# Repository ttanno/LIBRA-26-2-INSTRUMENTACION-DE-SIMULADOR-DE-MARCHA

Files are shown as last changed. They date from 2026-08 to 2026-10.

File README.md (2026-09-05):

# LIBRA — Instrumentación de Simulador de Marcha

**Plataforma móvil instrumentada para simulador de marcha**, orientada a la validación de prótesis transtibiales mediante sensórica embebida (IMU + celda de carga) y adquisición de datos sincronizada.

| | |
|---|---|
| **Curso** | DPB4 — Proyecto de Investigación |
| **Institución** | Pontificia Universidad Católica del Perú (PUCP) |
| **Alumno** | Alessandro Jesus Felix Tello |
| **Asesor** | Dante Angel Elias Giordano |
| **Estado** | En curso — Semana 4: pruebas de firmware de IMU (BNO055/MPU6050) y prototipos de referencia de posición absoluta (homing) para la plataforma |

---

## Índice

- [Descripción del proyecto](#descripción-del-proyecto)
- [Objetivos específicos](#objetivos-específicos)
- [Alcance](#alcance)
- [Nota de prioridad (Semana 3)](#nota-de-prioridad-semana-3)
- [Estructura del repositorio](#estructura-del-repositorio)
- [Estado del arte](#estado-del-arte)
- [Reportes semanales](#reportes-semanales)
- [Requerimientos técnicos derivados](#requerimientos-técnicos-derivados)

---

## Descripción del proyecto

En el laboratorio ya existe una plataforma mecánica de simulación de marcha (traslación horizontal por riel + cadena, traslación vertical por husillo y motor paso a paso, y un punto de flexo-extensión en el soporte de la prótesis), construida en un proyecto anterior. Este proyecto parte de esa base ya construida para **integrar sensores** (IMU y celda de carga), su electrónica de adquisición y un software de registro sincronizado, con el fin de validar prótesis transtibiales bajo cargas y cinemática trazables a normas ISO. El diseño mecánico puede implicar tanto soportes/adaptadores externos como modificaciones a la estructura existente, según lo que requiera la integración final de los sensores.

## Objetivos específicos

1. **Diseño mecánico** — Diseñar los soportes/adaptadores (y, de ser necesario, modificaciones a la estructura ya existente) para montar la IMU y la celda de carga, preservando la cinemática de la plataforma.
2. **Sistema electrónico** — Seleccionar e integrar sensores de bajo costo (IMU MEMS, celda de carga) dimensionados según las cargas de referencia de ISO 10328.
3. **Software** — Implementar adquisición continua y sincronizada (I2C/SPI para IMU, ADC dedicado para la celda de carga) con registro, visualización y almacenamiento.
4. **Validación** — Definir un protocolo de calibración y validación cruzada (IMU vs. encoder de la plataforma) anclado a ISO 7500-1 e ISO 22675.

## Alcance

La plataforma **sensa de forma continua** (registro/visualización) durante el uso de la prótesis en la simulación. **No** implementa un lazo de control en tiempo real (p. ej. un PID que retroalimente al simulador con los datos del sensor); esto queda como trabajo futuro. Esta distinción simplifica los requerimientos de software: no se exige baja latencia de lazo cerrado, solo sensado sincronizado y confiable.

## Estructura del repositorio

```
LIBRA/
├── Firmware/                           Sketches ESP32 (Arduino) y visores Python de prueba, por sensor/subsistema
│   ├── test_bno055/                    Prueba I2C + sobremuestreo del IMU BNO055, con visor en tiempo real
│   ├── test_mpu6050/                   Prueba del IMU MPU6050 con filtro complementario propio
│   ├── homing_absoluto/                Prototipo de cero absoluto del pivote por acelerómetro (persistente en flash)
│   └── homing_husillo_hall/            Prototipo de homing del eje del husillo con sensor Hall + imán
├── Estado-del-arte/                    Fichas de lectura, fuentes primarias (PDF) y la síntesis bibliográfica
│   ├── ISO/                            Normas y ensayos estructurales de prótesis
│   ├── REFERENCIA DE POSICION ABSOLUTA/  Arquitecturas de referencia absoluta sin goniómetro (CNC, robótica, laboratorios de marcha)
│   ├── SENSORES DE FUERZA/
│   │   ├── PYLON/                      Celda de carga en la interfaz pylon-plataforma: strain gauge, sensor magnético, comparativa de candidatas
│   │   └── GRF-AMTI/                   Plataforma de fuerza AMTI BP400600 (manuales, pinout, integración)
│   ├── SIMULADOR DE MARCHA/            Diseño mecánico de plataformas y bancos de prueba
│   ├── SOFTWARE/                       Arquitecturas de software embebido multi-sensor
│   ├── Revision bibliografica - Semana 1-2.md   Revisión bibliográfica consolidada (40 referencias, formato IEEE)
│   └── Sensores-LIBRA-Presentacion.pptx         Comparativa de sensores de fuerza, distancia y ángulo (soporte visual)
├── Evidencias/                         Fotos propias del equipo de laboratorio (no bibliográficas, reutilizables entre semanas)
│   ├── simulador/                      Simulador físico existente y método de marcadores M1-M4
│   ├── pruebas-imu-S4/                 Fotos de las pruebas de IMU (banco de protoboard) y del montaje sobre el pylon real (S4)
│   └── arquitectura-sensores-AMTI-S2.png   Diagrama de arquitectura de sensores por DOF (Semana 2)
├── Reportes-Semanales/                 Informes y reportes de avance, por semana
│   ├── S1/
│   │   ├── S1 - Informe Semanal...     Informe semanal (formato PUCP)
│   │   ├── S1 - Reporte de Avance...   Reporte de avance (formato PUCP)
│   │   └── Pendientes.md               Lista de trabajo de la S1 (cerrada; ítems abiertos trasladados a S3)
│   ├── S2/
│   │   ├── S2 - Informe Semanal...
│   │   ├── S2 - Reporte de Avance...
│   │   └── Resumen-Semana2.md          Resumen narrativo de la S2 (arquitectura por DOF, integración AMTI)
│   ├── S3/
│   │   └── Pendientes.md               Lista de trabajo de la S3 (cerrada; ítems abiertos trasladados a S4)
│   └── S4/
│       ├── Resumen-Semana4.md          Resumen narrativo de la S4 (pruebas de IMU y prototipos de homing)
│       └── Pendientes.md               Lista de trabajo activa (se actualiza semana a semana)
├── Plan de trabajo 1_DPB4 - Proyecto Simulador de marcha (2).pdf
└── README.md
```

## Estado del arte

La [revisión bibliográfica](./Estado-del-arte/Revision%20bibliografica%20-%20Semana%201-2.md) consolida el estado del arte en:

- Simuladores de marcha con sensórica embebida
- Concordancia entre IMU y sistemas ópticos de captura de movimiento
- Calibración y validación de IMU de bajo costo
- Celdas de carga y sensores fuerza-torque en prótesis y bancos de prueba
- Protocolos de calibración de instrumentación en sistemas robóticos/mecatrónicos
- Normas ISO de ensayo estructural de prótesis (ISO 10328, ISO 22675, ISO 7500-1)
- Arquitecturas de software para adquisición sincronizada multi-sensor
- Diseño mecánico de plataformas móviles y bancos de prueba
- Arquitectura electrónica de referencia y ubicación del sensor de fuerza (interfaz pylon–plataforma)
- Taxonomía de principios físicos de sensado de fuerza (strain gauge, magnético, capacitivo, FSR, piezoeléctrico, F/T comercial)

Cada referencia está trazada a su fuente y marcada según su nivel de verificación (confirmada por fuente primaria, corroboración cruzada, o pendiente de verificar). El documento incluye además una síntesis por objetivo específico y la brecha que justifica el proyecto.

Las fuentes originales (PDF y fichas en Markdown) están organizadas por tema en [`Estado-del-arte/`](./Estado-del-arte).

## Reportes semanales

En [`Reportes-Semanales/`](./Reportes-Semanales) se archivan, por semana, el informe de avance y el reporte semanal del proyecto (formato PUCP: resumen ejecutivo, actividades realizadas, planificado vs. ejecutado, dificultades, lecciones aprendidas y próximos pasos).

## Requerimientos técnicos derivados

Resumen de los requerimientos definidos a partir del estado del arte (detalle completo en la [revisión bibliográfica](./Estado-del-arte/Revision%20bibliografica%20-%20Semana%201-2.md#10-requerimientos-técnicos-derivados-cierre-de-semana-2)):

| Componente | Requerimiento orientativo |
|---|---|
| **IMU** | Sensor MEMS de bajo costo (MPU6050 / ICM-20948), muestreo ≥100 Hz, error objetivo <5° con calibración automática sensor-a-segmento |
| **Celda de carga (pylon)** | Rango dimensionado sobre ISO 10328 nivel P5 (≤100 kg): proof load 2240 N, ultimate 4480 N; no linealidad objetivo <8%. Ubicación: interfaz pylon–plataforma (no socket, no suelo), 1 eje axial. La candidata inicial (TAL107F-10kg) resultó subdimensionada — ver comparativa actualizada en [`Estado-del-arte/SENSORES DE FUERZA/PYLON/Comparativa-Sensores-Fuerza-Axial-Pylon.md`](./Estado-del-arte/SENSORES%20DE%20FUERZA/PYLON/Comparativa-Sensores-Fuerza-Axial-Pylon.md) |
| **Plataforma GRF (AMTI)** | AMTI BP400600 ya disponible en el laboratorio; lectura en tiempo real por salida analógica DB25S (Fx,Fy,Fz,Mx,My,Mz) hacia el mismo ADC (ADS1256), en paralelo a la celda de carga |
| **Software** | Adquisición continua por timestamp compartido, I2C/SPI + ADC dedicado, arquitectura modular para agregar sensores sin rediseño |
| **Validación** | Calibración estática/dinámica trazable (ISO 7500-1) + validación cruzada IMU vs. encoder de la plataforma, referenciada a ISO 22675 |
</content>

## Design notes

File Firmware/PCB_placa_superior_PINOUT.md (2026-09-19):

# Pinout de referencia — Placa superior (ESP32 + 2x VL53L1X + entrada HX711)

Referencia de conexionado para la placa que va **arriba** (ESP32-WROOM-32U +
los dos sensores de distancia ToF VL53L1X + entrada para el módulo HX711 +
borneras de tornillo para la celda de carga). El **BNO055 va en una placa
aparte**, montada abajo en la plataforma — no está en este documento (ver
`test_bno055/` y `test_bno055_oversampling/`).

Todos los datos de abajo están verificados contra hojas de datos/documentación
oficial (fuentes al final).

## 0. Topología general: el ESP32 es el único "cerebro"

No hay ningún microcontrolador en la placa de abajo — esa placa es solo el
BNO055 + un conector. **Todo** (HX711, los 2 ToF, y el BNO055) se conecta al
mismo ESP32 de la placa de arriba: HX711 y los ToF directo en la misma
placa, y el BNO055 por un cable/conector entre las dos placas.

Para el BNO055, en vez de compartir el mismo bus I2C de los ToF (que ya tiene
que manejar la secuencia de SHUT + reasignación de direcciones, y le llegaría
por un cable más largo entre placas, con más chance de ruido), conviene usar
el **segundo bus I2C que trae el ESP32** (tiene dos periféricos I2C
independientes por hardware) dedicado solo al BNO055:

| Señal | GPIO | Notas |
|---|---|---|
| SDA2 (bus dedicado al BNO055) | GPIO17 | libre, no strapping, no solo-entrada |
| SCL2 (bus dedicado al BNO055) | GPIO16 | libre, no strapping, no solo-entrada |

Así el BNO055 queda solo en su propio bus (sin competir por direcciones con
los ToF) y el conector entre las dos placas lleva 4 hilos: **3.3V, GND,
GPIO17 (SDA2), GPIO16 (SCL2)**.

## 1. ESP32-WROOM-32U DevKitC — pinout físico de 30 pines

Layout estándar del devkit de 30 pines (el mismo que aparece en el
esquemático, `U6`):

| Columna izquierda (de arriba hacia abajo) | Columna derecha (de arriba hacia abajo) |
|---|---|
| EN | 3V3 |
| VP (GPIO36, solo entrada) | GND |
| VN (GPIO39, solo entrada) | GPIO15 |
| GPIO34 (solo entrada) | GPIO2 |
| GPIO35 (solo entrada) | GPIO0 |
| GPIO32 | GPIO4 |
| GPIO33 | GPIO16 |
| GPIO25 | GPIO17 |
| GPIO26 | GPIO5 |
| GPIO27 | GPIO18 |
| GPIO14 | GPIO19 |
| GPIO12 | GND |
| GPIO13 | GPIO21 |
| GND | RX0 |
| VIN (5V) | TX0 |
| | GPIO22 |
| | GPIO23 |

**Pines a evitar para señales críticas de este diseño:**

- **Strapping pins (afectan el arranque):** GPIO0, GPIO2, GPIO5, GPIO12,
  GPIO15 — no usar para SHUT/XSHUT ni SCK si se puede evitar (un glitch en el
  arranque podría interferir con el modo de boot del ESP32).
- **Solo entrada (no pueden manejar salidas):** GPIO34, GPIO35, GPIO36 (VP),
  GPIO39 (VN) — no sirven para SCK (HX711) ni para SHUT (ToF), que necesitan
  ser salidas. Sí podrían usarse para una señal que solo se lee (ej. un INT
  de un ToF, si se decide rutearlo).
- **Reservados para la flash SPI interna (no exponer, no usar):** GPIO6-11 —
  no vienen en el header de este devkit de 30 pines, así que no aplica acá,
  pero importante no repetirlos si se diseña un módulo ESP32 "pelado" a
  futuro.

## 2. VL53L1X (sensor de distancia ToF, I2C) — pinout del breakout

Pinout típico de un breakout VL53L1X (I2C + XSHUT + interrupción), que
coincide con las etiquetas `VCC/GND/SDA/SCL/INT/SHUT` del esquemático (`U2`,
`U3`):

| Pin del breakout | Función | Notas |
|---|---|---|
| VCC (VIN) | Alimentación | Acepta 3V-5V en la mayoría de los breakouts (traen su propio regulador a la tensión del chip); revisar el datasheet específico del módulo `MYTOF400C-VL53L1X` antes de fijarlo, pero 3.3V del ESP32 es la opción segura |
| GND | Tierra | Común con el ESP32 |
| SCL | Reloj I2C | Al bus I2C del ESP32 (GPIO22 recomendado) — necesita resistencia pull-up (los breakouts suelen traerla integrada, ~10kΩ) |
| SDA | Datos I2C | Al bus I2C del ESP32 (GPIO21 recomendado) — mismo pull-up |
| INT (GPIO1 del chip) | Salida de interrupción, nivel 2.8V | Opcional — se puede dejar sin conectar (NC) si el firmware va a leer por *polling* en vez de por interrupción |
| SHUT (XSHUT) | Reset/apagado, **activo en bajo** | Nivel desplazado (compatible 3V/5V) — **imprescindible un GPIO independiente por cada sensor**, ver Secc. 4 |

**Dirección I2C:** los VL53L1X vienen todos con la dirección fija de fábrica
**0x29**. Como tenés **dos sensores idénticos en el mismo bus**, no se pueden
diferenciar solo por dirección — hay que usar el pin **SHUT** de cada uno
para reconfigurar la dirección de uno de los dos por software en el arranque
(secuencia típica: mantener ambos en reset, sacar a uno del reset,
reasignarle una dirección I2C distinta con `setAddress()` o equivalente de la
librería que se use, y recién ahí sacar al segundo del reset con la
dirección 0x29 que le queda por default).

## 3. HX711 (módulo breakout, no el chip pelado) — pinout

Ya documentado en detalle en
[`test_hx711/INSTRUCCIONES.md`](test_hx711/INSTRUCCIONES.md) — se repite acá
para tener todo junto:

| Pin del módulo (`XWF-HX711` en el esquemático) | Conexión |
|---|---|
| VCC | 3.3V del ESP32 (sin level shifter — ver justificación en `test_hx711/INSTRUCCIONES.md`) |
| GND | GND común |
| DT (DOUT) | GPIO del ESP32, entrada — GPIO32 en el sketch actual |
| SCK (CLK) | GPIO del ESP32, salida — GPIO33 en el sketch actual |
| E+ / E- | A la bornera de tornillo → Rojo/Negro de la celda de carga (excitación) |
| A+ / A- | A la bornera de tornillo → Verde/Blanco de la celda de carga (señal, canal A) |
| B+ / B- | Libres (canal B, ganancia fija 32 — para una segunda celda si hiciera falta) |

**Código de colores de la celda de carga (4 hilos):** Rojo=EXC+, Negro=EXC-,
Verde=SIG+, Blanco=SIG- (verificar contra el datasheet de la celda que se
termine usando — no es 100% universal entre fabricantes).

## 4. Asignación de pines recomendada para esta placa

Juntando todo lo anterior, evitando strapping pins y pines de solo-entrada:

| Señal | GPIO ESP32 | Justificación |
|---|---|---|
| I2C SDA (compartido, ambos ToF) | GPIO21 | pin I2C por default del ESP32 |
| I2C SCL (compartido, ambos ToF) | GPIO22 | pin I2C por default del ESP32 |
| SHUT ToF1 (U3) | GPIO25 | salida, no strapping |
| SHUT ToF2 (U2) | GPIO26 | salida, no strapping |
| HX711 DT | GPIO32 | ya usado en `test_hx711.ino`, mantiene el firmware actual sin cambios |
| HX711 SCK | GPIO33 | ya usado en `test_hx711.ino`, mantiene el firmware actual sin cambios |
| INT ToF1 / ToF2 (opcional) | sin conectar (NC), o GPIO27/GPIO14 si se decide usar interrupciones | no hace falta para lectura por polling |
| I2C SDA2 (bus dedicado, BNO055 en la otra placa) | GPIO17 | segundo periferico I2C del ESP32, ver Secc. 0 |
| I2C SCL2 (bus dedicado, BNO055 en la otra placa) | GPIO16 | segundo periferico I2C del ESP32, ver Secc. 0 |

Con esta asignación, GPIO0/2/5/12/15 (strapping) y GPIO34/35/36/39 (solo
entrada) quedan libres para lo que haga falta después (ej. UART/JTAG de
debug, otro sensor, etc.) sin comprometer el arranque del ESP32 ni necesitar
salidas donde no se puede.

## 5. Siguiente paso

- Confirmar en el datasheet específico del módulo `MYTOF400C-VL53L1X` (no
  solo el chip VL53L1X genérico) el rango de alimentación exacto y si trae
  pull-ups I2C integradas, antes de rutear VCC/SDA/SCL en la placa.
- Escribir el sketch de prueba para los dos VL53L1X con secuencia de
  SHUT + reasignación de dirección I2C (pendiente, ver conversación del
  Firmware — análogo a como se hizo `test_hx711.ino` para la celda).

### Fuentes consultadas

- [ESP32-DevKitC V4 Pinout Diagram + Safe GPIOs](https://esp32.co.uk/esp32-devkitc-v4-pinout-diagram-safe-gpios/) (categorías de pines: input-only, strapping, flash)
- [ESP32 Pinout Reference — Last Minute Engineers](https://lastminuteengineers.com/esp32-pinout-reference/) (layout físico de 30 pines izquierda/derecha)
- [Adafruit VL53L1X — Pinouts](https://learn.adafruit.com/adafruit-vl53l1x/pinouts) (VIN/GND/SCL/SDA/GPIO(INT)/XSHUT, dirección I2C 0x29, nivel logico de XSHUT)
- `Firmware/test_hx711/INSTRUCCIONES.md` (pinout del módulo HX711 y de la celda de carga, ya verificado en este mismo proyecto)

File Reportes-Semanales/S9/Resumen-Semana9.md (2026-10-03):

# Resumen de trabajo — Semana 9

**Período:** 26/09/2026 – 02/10/2026
**Responsable:** Alessandro Jesus Felix Tello

Foco de la semana: diagnóstico y reparación de la conexión del BNO055 tras el cambio de pinout de la S9 (bus I2C dedicado GPIO17/16), calibración del acelerómetro, y una caracterización completa de linealidad/exactitud/histéresis del sensor en todo su rango de interés (0-60°) usando el soporte de arco indexado construido para esto. Se cierra con una simulación de un filtro de corrección lineal y cuánto reduciría el error.

---

## 1. Diagnóstico y reparación de la conexión del BNO055

Al retomar las pruebas sobre el nuevo pinout (`SDA→GPIO17`, `SCL→GPIO16`, bus `Wire1` dedicado — ver `Firmware/PCB_placa_superior_PINOUT.md`), el sensor dejó de responder. El diagnóstico se hizo leyendo el puerto serial directamente y forzando reseteos controlados, en vez de asumir la causa:

1. **Primer síntoma: cero datos por serial**, ni siquiera el mensaje de arranque del sketch. Se descartó un problema de software leyendo el puerto crudo.
2. **Con reset manual (botón físico):** apareció un bucle de **brownout** (`E BOD: Brownout detector was triggered`) — el ESP32 se reseteaba solo por voltaje insuficiente, antes de terminar el `setup()`. Resuelto cambiando de cable/puerto USB (el reset automático por DTR/RTS tampoco funcionaba en esta placa — hay que usar el botón físico).
3. **Con el ESP32 ya estable:** `ERROR: no se detectó el BNO055`. Se verificó el pinout contra el sketch y se aisló el problema desconectando el sensor por completo (arranque limpio sin él, confirmando que no era un problema general de la placa).
4. **Causa raíz encontrada:** un cable había quedado conectado al pin **INT** del BNO055 en vez de a uno de los 4 pines que usa el diseño (VCC, GND, SDA, SCL) — el diseño de LIBRA deja INT, BOOT, PS1, PS0, BL_IND y RST sin conectar a propósito. Corregido el cableado, el sensor volvió a dar datos limpios y estables.

**Lectura:** la mayoría de las "desconexiones" a lo largo de la semana durante las pruebas de ángulos (ver Secc. 3) fueron reincidencias del mismo tipo de problema (cable flojo por el manipuleo constante del soporte), no un problema del sensor o del firmware.

---

## 2. Calibración del acelerómetro (6 posiciones)

Con la conexión ya estable, se corrió `calibrar_acelerometro.py` (apoyar el sensor quieto en 6 orientaciones — las 6 caras de un cubo imaginario). Resultado: `Calib[sys,gyro,accel,mag]` pasó de **0,3,0,0** a **2,3,3,3** — acelerómetro y magnetómetro quedaron en calibración completa (antes sin calibrar). El offset queda guardado en la flash del ESP32, no hace falta repetirlo en cada encendido.

---

## 3. Prueba de linealidad, exactitud e histéresis (0-60°)

### 3.1 Metodología

Usando el soporte de arco indexado (`Firmware/test_wifi_ap_bno055/soporte_angulos_imu/`, 13 posiciones de 0 a 60° cada 5°), se construyó `prueba_angulos_conocidos.py` para automatizar la toma de datos:

- **Disparo automático:** en vez de adivinar cuándo el sensor ya está quieto en la nueva posición, el script exige ver primero que el sensor **se movió** (std > 1.5°) y recién después que **volvió a quedar quieto** (std < 0.05°) antes de arrancar a grabar 30 s. Esto corrigió un bug de la primera versión, que podía disparar la grabación con el sensor todavía en la posición anterior si ya estaba quieto desde antes.
- **Eje usado:** `roll`, no `pitch` — confirmado con datos reales que, con el montaje actual del IMU sobre la plataforma, pitch se queda prácticamente plano (174-176°) sin importar el ángulo aplicado, mientras que roll sí responde.
- **Diseño del experimento:** los 13 ángulos (0° a 60°, cada 5°), con 3 repeticiones cada uno, en **ambas direcciones** (subida 0→60° y bajada 60→0°) — 78 mediciones en total. Repetir en ambas direcciones permite medir histéresis (holgura mecánica del soporte); repetir 3 veces por ángulo permite separar ruido de una captura puntual del error real, y habilita un test de falta de ajuste para la linealidad.
- Varias posiciones se tuvieron que repetir por los cortes de conexión de la Secc. 1 — los archivos descartados (incompletos o con ruido alto) están documentados en el propio script de procesamiento (`Firmware/test_wifi_ap_bno055/visor_python/analizar_linealidad.py`, diccionario `MAPA`).

### 3.2 Resultados

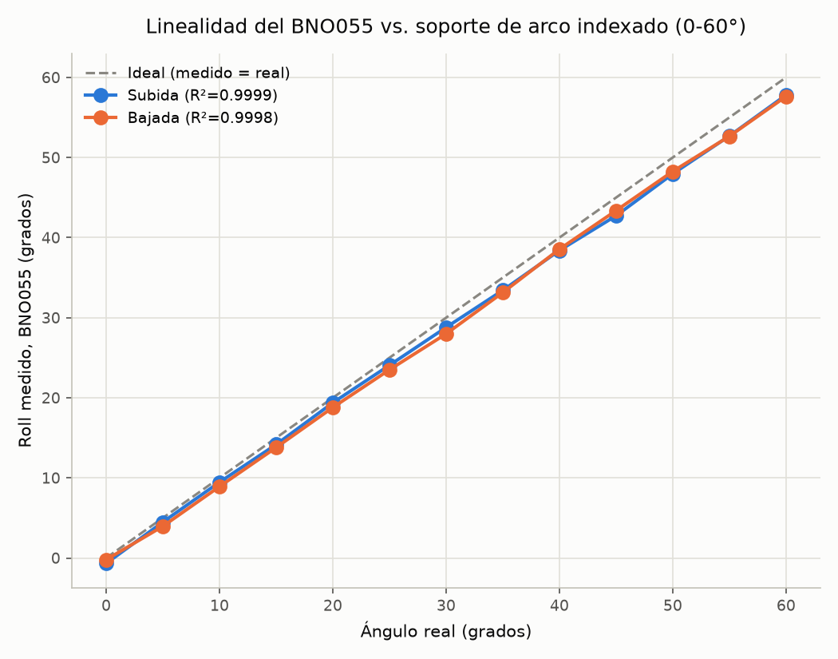
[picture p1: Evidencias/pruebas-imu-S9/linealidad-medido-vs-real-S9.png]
Linealidad: medido vs. real
|  |
|---|
| Roll medido vs. ángulo real, subida y bajada, con la recta ideal (medido = real) de referencia |

- **Linealidad: excelente.** R² = 0.9999 (subida) y 0.9998 (bajada) — la relación entre el ángulo real y la lectura del BNO055 es prácticamente una recta en todo el rango, sin curvatura visible.
- **Pero hay un error sistemático de escala (~3%):** la pendiente de ambas rectas es 0.966-0.973 en vez de 1.0. El error no es un offset fijo — crece proporcional al ángulo: de -0.2 a -0.7° cerca de 0°, hasta -2.2 a -2.4° cerca de 60°.
- **Histéresis: pequeña y sin dirección dominante.** Diferencia media subida-bajada = +0.18° (std 0.44°) — el signo cambia según el ángulo, no hay un patrón de backlash sistemático claro. Queda dentro del rango de ruido entre repeticiones.
- **Un punto con ruido alto para anotar:** a 45° en bajada, la desviación estándar entre repeticiones fue 0.47° (vs. 0.03-0.2° en el resto de los puntos) — no se descartó, pero vale la pena repetirlo si se vuelve a tomar data.

### 3.3 Simulación: filtro de corrección lineal

Como el error crece de forma lineal con el ángulo (no es ruido aleatorio), se simuló corregirlo con la propia recta de calibración obtenida (pool subida+bajada, 26 puntos): `ángulo_corregido = (roll_medido − (−0.514)) / 0.9697`.

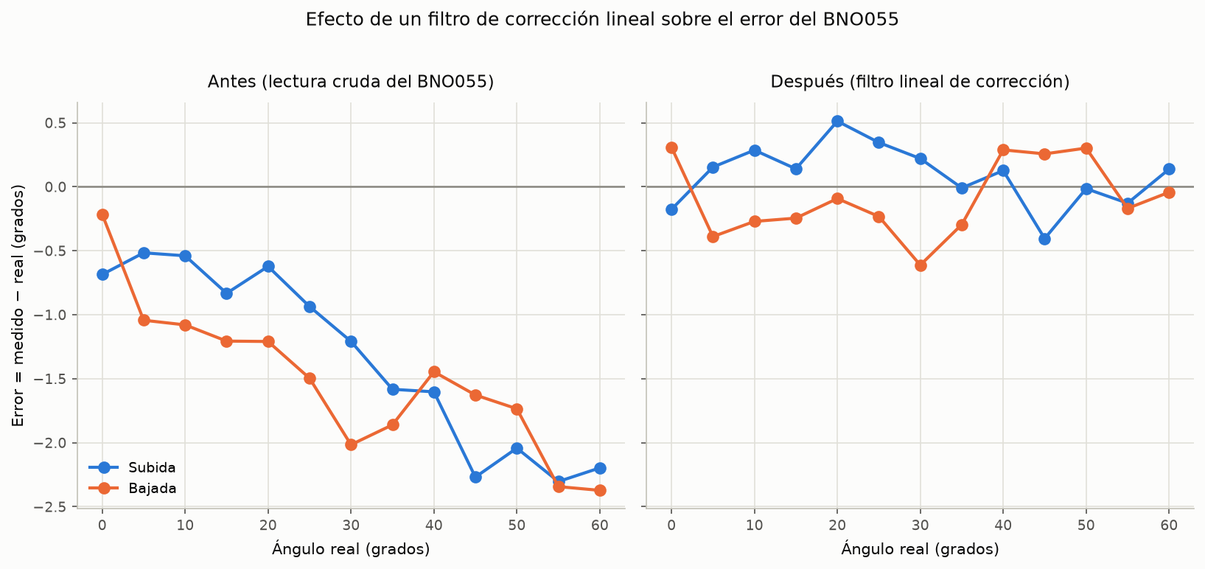
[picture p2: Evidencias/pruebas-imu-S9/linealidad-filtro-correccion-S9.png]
Efecto del filtro de corrección
|  |
|---|
| Error antes (lectura cruda) y después (filtro lineal) de aplicar la corrección, subida y bajada |

**Resultado de la simulación:** el error máximo baja de **~2.4°** (lectura cruda, en 55-60°) a **~0.5°** (corregido) — una reducción de más de 4×, y el error corregido ya no crece con el ángulo (queda disperso alrededor de 0, reflejo del ruido/histéresis de ±0.4° medido en la Secc. 3.2, no de un sesgo sistemático restante).

**Pendiente:** este filtro todavía es un cálculo en post-procesamiento (Python), no está aplicado en el firmware del ESP32. Si se confirma que sigue siendo válido con más datos, se puede escribir directo en el sketch (una resta y una división sobre `roll` antes de usarlo en el resto del sistema).

---

## 4. Diseño CAD preliminar del adaptador del sensor de fuerza

Primer diseño del adaptador que monta la celda de carga del pylon entre las dos placas (4 parantes + mordaza central para la celda), pensado junto con la sugerencia de protección contra cizalla de la Secc. 5.

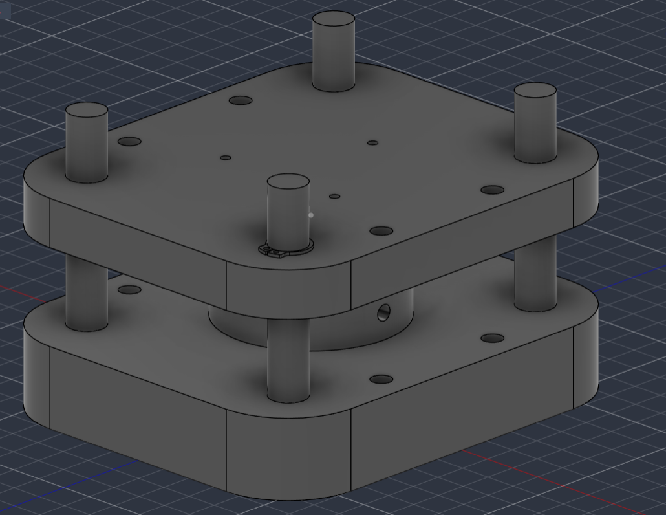
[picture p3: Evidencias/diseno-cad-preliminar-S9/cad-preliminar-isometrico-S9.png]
Vista isométrica del adaptador
|  |
|---|
| Vista isométrica: placas superior e inferior, 4 parantes y mordaza central de la celda de carga |

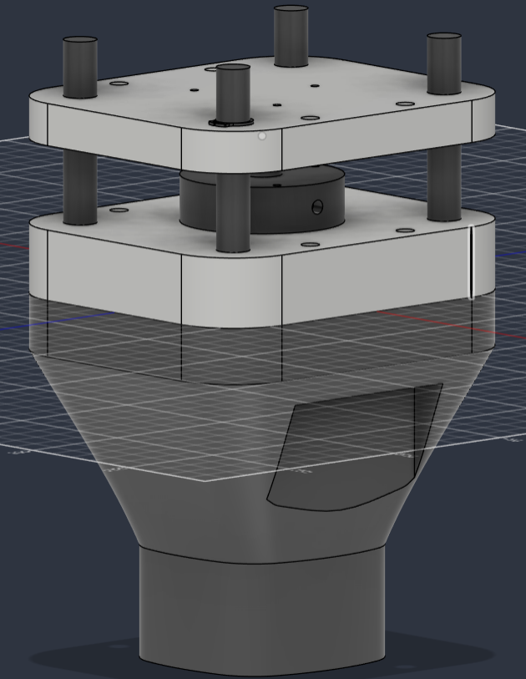
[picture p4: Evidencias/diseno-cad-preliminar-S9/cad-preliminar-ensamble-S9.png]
Ensamble con el pylon
|  |
|---|
| Ensamble preliminar del adaptador sobre la estructura cónica del pylon |

**Pendiente:** es un diseño preliminar — falta definir el patrón de pernos contra la celda de carga real, verificar holguras de los parantes, y evaluar ahí mismo si conviene integrar las barras guía de cizalla de la Secc. 5.

---

## 5. Otras notas

Se recibió una sugerencia (30/09) sobre proteger la celda de carga del pylon contra esfuerzos de cizalla con barras guía laterales — quedó documentada como pendiente de evaluar en `Reportes-Semanales/S9/Pendientes.md`, sin trabajo activo esta semana.

---

## Fuentes

- `Firmware/test_wifi_ap_bno055/test_wifi_ap_bno055.ino` — sketch con el pinout corregido (`Wire1`, GPIO17/16).
- `Firmware/test_wifi_ap_bno055/soporte_angulos_imu/` — diseño CAD del soporte de arco indexado (CadQuery).
- `Firmware/test_wifi_ap_bno055/visor_python/prueba_angulos_conocidos.py` — script de captura con disparo automático por movimiento+quietud.
- `Firmware/test_wifi_ap_bno055/visor_python/calibrar_acelerometro.py` — calibración de 6 posiciones.
- `Firmware/test_wifi_ap_bno055/visor_python/analizar_linealidad.py` — procesamiento: regresión, R², histéresis, simulación del filtro, generación de gráficos.
- `Firmware/test_wifi_ap_bno055/visor_python/resumen_linealidad_S9.csv` — tabla completa (dirección, ángulo, promedio, error, std, repeticiones).
- `Evidencias/pruebas-imu-S9/` — gráficos de linealidad y del efecto del filtro de corrección.
- `Evidencias/diseno-cad-preliminar-S9/` — vistas del diseño preliminar del adaptador del sensor de fuerza.

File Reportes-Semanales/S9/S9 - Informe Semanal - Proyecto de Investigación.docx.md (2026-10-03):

**INFORME SEMANAL DE AVANCE DEL PROYECTO DE INVESTIGACIÓN**

**Proyecto:** Diseño e integración de una plataforma móvil que incluya sensores para medir variables cinemáticas y cinéticas en un simulador de marcha para validar prótesis transtibiales

**Período del informe:** 26/09/2026 al 02/10/2026

**Responsable:** Alessandro Jesus Felix Tello

**1. Resumen Ejecutivo**

Semana centrada en el IMU (BNO055): se diagnosticó y resolvió una falla de conexión (cable en el pin INT en vez de SDA/SCL), se calibró el acelerómetro, y se corrió una caracterización completa de linealidad/exactitud/histéresis en 0-60°. Resultado: muy buena linealidad (R²>0.999) con un error de escala sistemático de ~3%, corregible con un filtro lineal simple. También se avanzó un primer diseño CAD del adaptador del sensor de fuerza.

**2. Actividades Realizadas**

1. **Diagnóstico y reparación del BNO055:** aislado paso a paso (brownout de alimentación → sensor no detectado → cable mal puesto en INT). Conexión estable de nuevo.
2. **Calibración de 6 posiciones del acelerómetro:** `Calib[accel,mag]` pasó de 0/3 a 3/3.
3. **Prueba de linealidad 0-60°:** 13 ángulos × 3 repeticiones × 2 direcciones (subida/bajada) con el soporte de arco indexado, usando un script con disparo automático por movimiento+quietud.
4. **Simulación de filtro de corrección lineal:** reduce el error máximo de ~2.4° a ~0.5°.
5. **Primer diseño CAD del adaptador del sensor de fuerza** (parantes + mordaza para la celda de carga del pylon).

**3. Actividades Planificadas vs. Actividades Ejecutadas**

| Actividad Planificada | Estado | Comentarios |
| :---- | :---- | :---- |
| Aplicar fix del EMA, corregir falso contacto y repetir pruebas del BNO055 | Ejecutada | El "falso contacto" resultó ser un cable en el pin INT; resuelto |
| Calibración de acelerómetro y prueba de linealidad 0-60° (parte del plan de repetir pruebas del BNO055) | Ejecutada | R²>0.999 ambas direcciones; error de escala ~3% corregible con filtro lineal |
| *(no planificada)* Diseño CAD preliminar del adaptador de fuerza | Ejecutada | — |

**4. Dificultades o Problemas Presentados**

La reconexión intermitente del BNO055 durante la toma de datos (manipuleo constante del soporte de ángulos) obligó a repetir varias posiciones de la prueba de linealidad — documentado en el propio script de procesamiento. No bloqueó el resultado final, solo alargó la toma de datos.

**5. Lecciones Aprendidas / Recomendaciones**

Diagnosticar leyendo el puerto serial crudo (en vez de asumir la causa) permitió separar tres problemas distintos que se presentaban juntos: alimentación (brownout), pinout (I2C) y un cable en el pin equivocado (INT). Verificar con datos reales qué eje del IMU responde al movimiento (roll, no pitch, con este montaje) evitó construir una tabla de resultados sin sentido.

**6. Actividades Planificadas para la Siguiente Semana**

| Actividad | Objetivo |
| :---- | :---- |
| Atender las observaciones pendientes de la S7 (estructura del pylon, reprogramación, trazabilidad, migración a Drive) | — |
| Aplicar el filtro de corrección lineal del roll en el firmware | Objetivo específico 2 |
| Avanzar el diseño CAD del adaptador de fuerza (patrón de pernos, holguras) | Objetivo específico 1 |
| Evaluar la propuesta de barras guía contra cizalla para la celda de carga | Objetivo específico 1 |

**7. Anexos o Evidencias**

Documento [Resumen-Semana9.md](https://github.com/ttanno/LIBRA-26-2-INSTRUMENTACION-DE-SIMULADOR-DE-MARCHA/blob/main/Reportes-Semanales/S9/Resumen-Semana9.md) (detalle técnico completo). Evidencias en [Evidencias/pruebas-imu-S9/](https://github.com/ttanno/LIBRA-26-2-INSTRUMENTACION-DE-SIMULADOR-DE-MARCHA/tree/main/Evidencias/pruebas-imu-S9) y [Evidencias/diseno-cad-preliminar-S9/](https://github.com/ttanno/LIBRA-26-2-INSTRUMENTACION-DE-SIMULADOR-DE-MARCHA/tree/main/Evidencias/diseno-cad-preliminar-S9). Scripts en [Firmware/test_wifi_ap_bno055/visor_python/](https://github.com/ttanno/LIBRA-26-2-INSTRUMENTACION-DE-SIMULADOR-DE-MARCHA/tree/main/Firmware/test_wifi_ap_bno055/visor_python).

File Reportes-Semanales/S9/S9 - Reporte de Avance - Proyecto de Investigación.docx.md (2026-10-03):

**REPORTE DE AVANCE – PROYECTO DE INVESTIGACIÓN EN LIBRA**

| INFORMACIÓN GENERAL | |
| :---- | :---- |
| Título del Proyecto | Diseño e integración de una plataforma móvil que incluya sensores para medir variables cinemáticas y cinéticas en un simulador de marcha para validar prótesis transtibiales |
| Nombre del alumno/a | Alessandro Jesus Felix Tello |
| Nombre del asesor/a | Dante Angel Elias Giordano |
| Laboratorio de Investigación | Laboratorio de Investigación en Biomecánica y Robótica Aplicada |
| Fecha de entrega | 02/10/2026 |

**Objetivos (general y específicos) del proyecto de investigación ejecutado en LIBRA**

| Objetivo | Nivel Avance (%) |
| :---- | :---- |
| OG: Diseñar e integrar una plataforma móvil instrumentada con sensores para medir variables cinemáticas y cinéticas en un simulador de marcha, para apoyar la validación experimental de prótesis transtibiales | 36% *(propuesto — ajustar según tu criterio)* |
| OE1: Diseño Mecánico — diseñar la plataforma móvil considerando los requerimientos mecánicos y funcionales del simulador | 23% *(propuesto — ajustar según tu criterio)* |
| OE2: Sistema Electrónico — seleccionar e integrar sensores y sistema electrónico de adquisición y procesamiento | 50% *(propuesto — ajustar según tu criterio)* |
| OE3: Software — desarrollar el software para sincronizar, visualizar, registrar y gestionar los datos del sistema | 17% *(propuesto — ajustar según tu criterio)* |
| OE4: Validación — calibrar y validar la plataforma mediante pruebas experimentales | 20% *(propuesto — ajustar según tu criterio)* |

**Resultados del proyecto de investigación ejecutado en LIBRA**

| Resultado | Nivel Avance (%) |
| :---- | :---- |
| R1: Plataforma diseñada e integrada al simulador | 22% *(propuesto — ajustar según tu criterio)* |
| R2: Sistema de sensores (cinemáticos y cinéticos) operativo | 37% *(propuesto — ajustar según tu criterio)* |
| R3: Sistema electrónico de adquisición de datos en tiempo real | 21% *(propuesto — ajustar según tu criterio)* |
| R4: Software de monitoreo, almacenamiento y visualización | 8% *(propuesto — ajustar según tu criterio)* |

**Síntesis de lo ejecutado durante la semana**

| Actividad | Objetivo | Descripción | Resultados |
| :---- | :---- | :---- | :---- |
| A1: Diagnóstico y reparación del BNO055 | OE2 | Aislamiento sistemático de 3 fallas encadenadas: brownout de alimentación, pinout I2C, cable en pin INT | Conexión estable restaurada; causa raíz documentada |
| A2: Calibración de 6 posiciones del acelerómetro | OE2/OE4 | Offset guardado en flash del ESP32 | `Calib[accel,mag]` de 0/3 a 3/3 |
| A3: Prueba de linealidad 0-60° (subida/bajada) | OE4 | 13 ángulos × 3 repeticiones × 2 direcciones con soporte de arco indexado; script con disparo automático por movimiento+quietud | R²>0.999 ambas direcciones; error de escala sistemático ~3%; histéresis pequeña (+0.18°±0.44°) |
| A4: Simulación de filtro de corrección lineal | OE2/OE4 | Corrección post-procesamiento sobre los datos de A3 | Error máximo reducido de ~2.4° a ~0.5° |
| A5: Diseño CAD preliminar del adaptador de fuerza | OE1 | Parantes + mordaza central para la celda de carga del pylon | Primer modelo 3D, pendiente definir patrón de pernos y holguras |

**Situaciones surgidas en el desarrollo del proyecto**

| Eventos | Fecha de Ocurrencia | Actividad Afectada | Acciones Tomadas |
| :---- | :---- | :---- | :---- |
| E1: Interrupciones intermitentes de la conexión del BNO055 (cables sueltos por el manipuleo del soporte de ángulos) | F1: 28/09/2026 – 02/10/2026 | A1: Prueba de linealidad 0-60° (subida/bajada) | Diagnóstico sistemático por puerto serial (reset manual, lectura cruda) y corrección del cableado; se repitieron las posiciones afectadas, sin perder el resultado final |
| E2: No se llegó a integrar el sensor de fuerza con el adaptador preliminar porque no se habían previsto las fuerzas de cizalla sobre la celda de carga | F2: 30/09/2026 | A2: Integración del sensor de fuerza al adaptador del pylon | Se documentó como pendiente evaluar barras guía de cizalla antes de integrar (ver `Reportes-Semanales/S9/Pendientes.md`); la integración queda para cuando esté resuelto ese punto |

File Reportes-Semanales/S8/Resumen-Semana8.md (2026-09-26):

# Resumen de trabajo — Semana 8

**Período:** 19/09/2026 – 25/09/2026
**Responsable:** Alessandro Jesus Felix Tello

Foco de la semana: (1) diseño de la PCB de la placa superior y del breakout del BNO055; (2) sensor de fuerza, con buenos resultados en la calibración del HX711; (3) prueba de los 2 sensores ToF VL53L1X, pendiente desde la S7; (4) dos documentos de estado del arte (IMU de bajo drift y control de fuerza con celda + IMU usando el AMTI como referencia).

> **Nota sobre las observaciones de la S7:** esta semana no se atendieron las observaciones del Dr. Dante Elías sobre el informe de la S7 (EMA y falso contacto del BNO055, comparación HX711 vs. ADS1256, reprogramación de actividades, definición de la "estructura del pylon", trazabilidad de pruebas y migración del repositorio al Drive de LIBRA). Fue por una mala organización de mi parte. **Estas observaciones serán lo primero que se trabaje en la S9** (ver "Plan para la S9").

---

## 1. Diseño de PCB

### 1.1 Placa superior (ESP32)

El esquemático se organizó por bloques funcionales: **microcontrolador ESP32**, **IMU** (conector hacia el breakout del BNO055), **HX711** (entrada de la celda de carga por bornera), **alimentación** (bornera de 2 pines), **sensor Hall** (homing del husillo) y **2 sensores ToF VL53L1X**. El pinout está en `Firmware/PCB_placa_superior_PINOUT.md`.

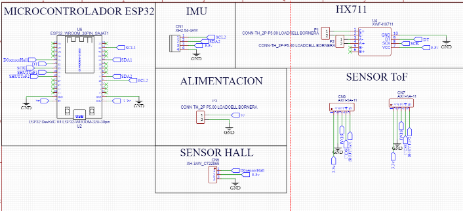
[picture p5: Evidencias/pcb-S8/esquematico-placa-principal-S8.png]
Esquemático de la placa superior, por bloques
|  |
|---|
| Esquemático de la placa superior: ESP32, IMU, HX711, alimentación, sensor Hall y ToF |

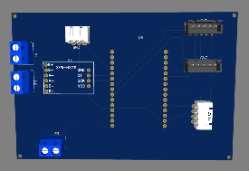
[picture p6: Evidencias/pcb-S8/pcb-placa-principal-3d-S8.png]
Vista 3D de la placa superior
|  |
|---|
| Vista 3D de la placa superior: borneras (alimentación y celda), módulo HX711, zócalo del ESP32 y conectores de IMU/ToF |

### 1.2 Breakout del BNO055 (DFRobot SEN0374)

Placa aparte para el BNO055. Lleva **3 conectores XH 2.54 de 4 pines** (VCC, GND, SCL, SDA) en paralelo, así el bus I2C entra por uno y se puede encadenar a otros módulos. Los pines BOOT, PS1, PS0, BL_IND, RST e INT quedan sin conectar. Usar conectores XH con traba, en vez de cables sueltos, también apunta al **falso contacto** que se detectó en la S7.

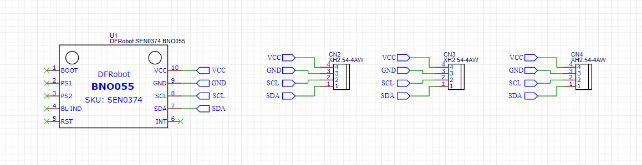
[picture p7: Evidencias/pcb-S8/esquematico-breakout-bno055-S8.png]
Esquemático del breakout del BNO055
|  |
|---|
| Esquemático del breakout: BNO055 con 3 conectores XH de 4 pines en paralelo |

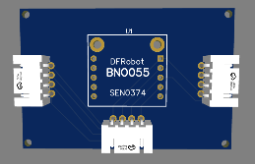
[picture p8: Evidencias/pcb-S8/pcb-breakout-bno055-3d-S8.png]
Vista 3D del breakout del BNO055
|  |
|---|
| Vista 3D del breakout del BNO055 |

**Pendiente:** revisión del diseño antes de fabricar (DRC, anchos de pista de alimentación, ubicación de agujeros de montaje).

---

## 2. Sensor de fuerza: HX711

Se graficaron los resultados de la prueba con masa patrón (datos de `Evidencias/pruebas-fuerza-S7/entendiendo-cuentas-hx711-S7.csv`):

- En vacío, las cuentas crudas son estables alrededor de la tara (−22864.8 cuentas).
- Con la masa patrón de 2 kg se obtiene un factor de **0.001098 N/cuenta**, que da **19.61 N** (esperado: 19.61 N).
- Al quitar la carga vuelve a **0.016 N** (≈0).
- Una masa de verificación, **sin recalibrar**, da **9.84 N (≈1.004 kg)** y cae sobre la recta de calibración.

La celda y el cableado responden de forma lineal y repetible con el HX711.

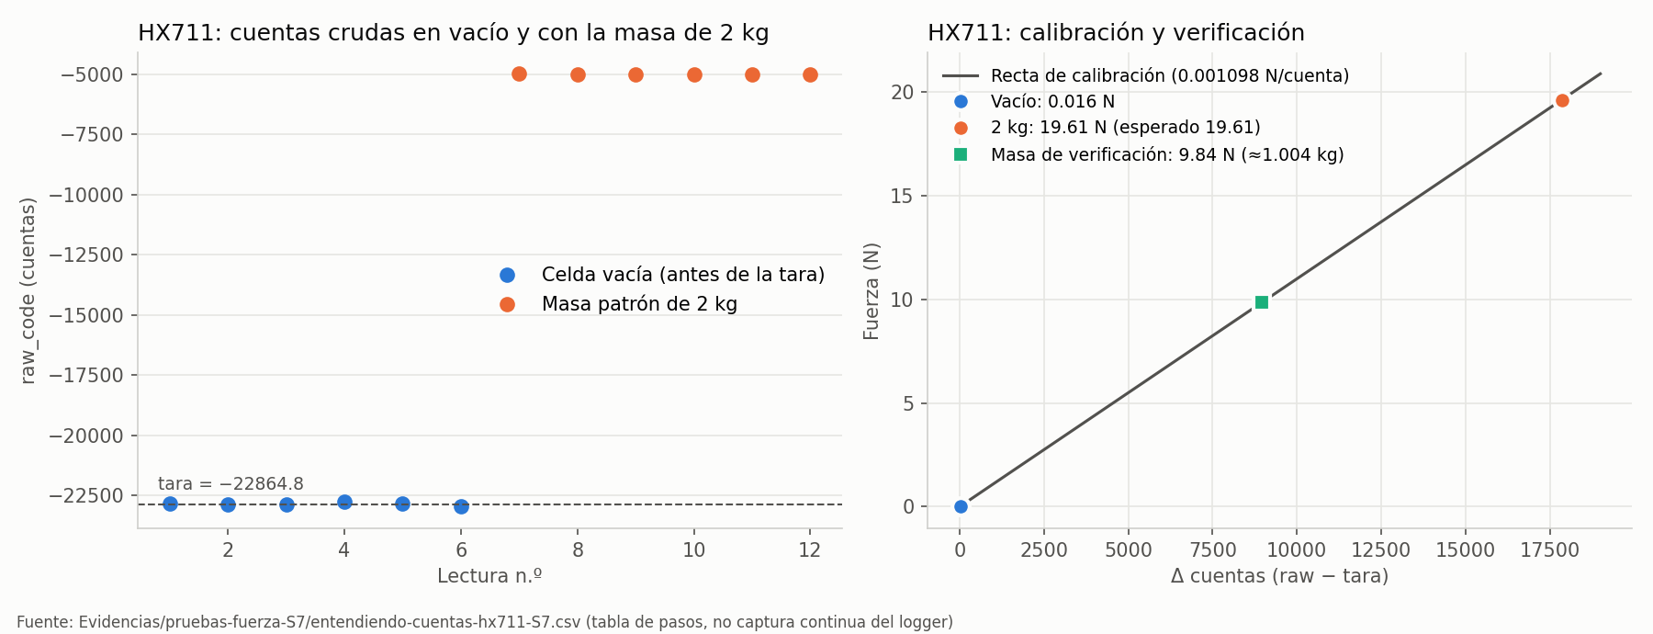
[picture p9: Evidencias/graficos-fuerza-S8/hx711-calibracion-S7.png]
Calibración y verificación del HX711
|  |
|---|
| Izq.: cuentas crudas en vacío y con 2 kg. Der.: recta de calibración con los puntos de vacío, 2 kg y masa de verificación |

---

## 3. Sensores de distancia ToF (2x VL53L1X)

Se escribió `Firmware/test_tof/test_tof.ino` (+ `INSTRUCCIONES.md` y visores en `visor_python/`) con la librería VL53L1X de Pololu. Pinout: I2C compartido en GPIO21/22 y SHUT individual en GPIO25 (ToF1/U3) y GPIO26 (ToF2/U2).

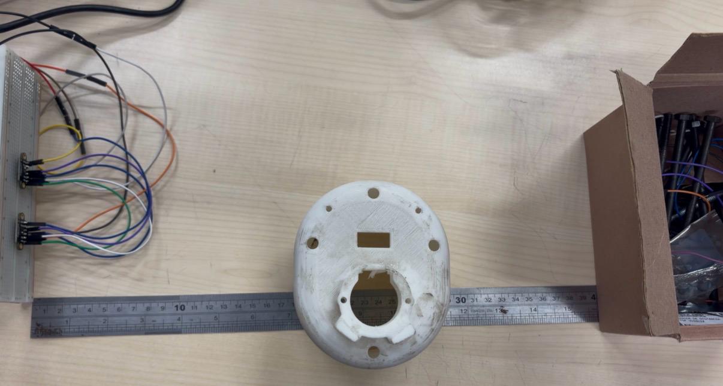
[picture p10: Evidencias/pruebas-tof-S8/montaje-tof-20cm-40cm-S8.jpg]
Montaje de prueba de los 2 ToF a 20 y 40 cm
|  |
|---|
| Montaje físico de la prueba de los 2 sensores ToF VL53L1X a distancias conocidas |

### 3.1 Reasignación de dirección I2C, confirmada en hardware

Los dos VL53L1X salen de fábrica con la misma dirección (0x29). El sketch saca primero a ToF1 del reset y le asigna 0x30; después saca a ToF2, que se queda en 0x29. En el ESP32 real, el escaneo I2C mostró **ambas direcciones (0x29 y 0x30)**.

### 3.2 Primera medición a distancia conocida

~20 s de captura, `status=0` (lectura válida) en toda la prueba:

| Sensor | Distancia esperada | Promedio medido | Desv. estándar | Rango | Error |
|---|---|---|---|---|---|
| ToF1 (0x30) | 400 mm | **408.4 mm** | 11.8 mm | 399–444 mm | +8.4 mm (+2.1 %) |
| ToF2 (0x29) | 200 mm | **219.5 mm** | 4.8 mm | 211–229 mm | +19.5 mm (+9.75 %) |

n = 213 muestras válidas por sensor (~10.8 Hz). Datos: `Evidencias/pruebas-tof-S8/tof_20cm_40cm_prueba1.csv`.

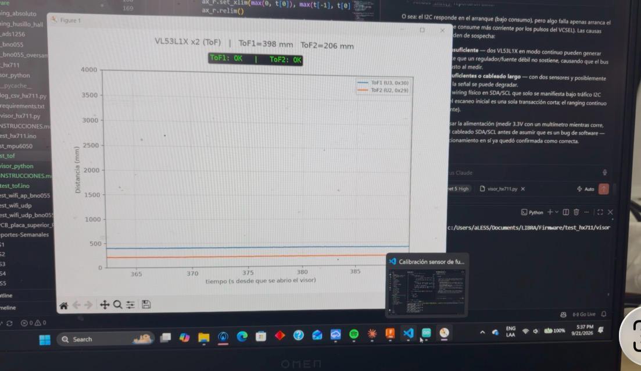
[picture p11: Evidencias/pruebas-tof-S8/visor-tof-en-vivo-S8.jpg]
Visor en vivo de los 2 ToF durante la prueba
|  |
|---|
| Visor en vivo (`visor_python/`) durante la captura, con ToF1=398 mm y ToF2=206 mm |

Los dos sensores distinguen bien las distancias. El sesgo relativo más alto a 20 cm coincide con el offset fijo de fábrica del VL53L1X, que pesa más a corta distancia. Se puede corregir con `calibrateOffset()`.

**Nota metodológica:** la primera pasada incluía ~1740 filas viejas del buffer serial. Se filtraron por el ritmo de muestreo real y se agregó `reset_input_buffer()` a los visores. También se corrigió un `UnicodeEncodeError` que detenía el hilo de lectura del visor.

---

## 4. Estado del arte

### 4.1 IMU de bajo drift: corrección (21/09)

Se agregó la Sección 7 a `Estado-del-arte/REFERENCIA DE POSICION ABSOLUTA/Comparativa-IMU-Bajo-Drift.md`. Aclara que el sensor en uso **desde la S6 es el BNO055** (DFRobot SEN0374) y no el MPU6050 de las secciones anteriores. La decisión de migrar a LSM6DSR/ICM-45686 sigue abierta y se evaluará contra el BNO055 ya calibrado.

### 4.2 Control de fuerza con celda + IMU usando el AMTI como referencia (24/09)

Nuevo documento: `Estado-del-arte/CONTROL DE FUERZA/Control-GRF-celda-IMU-vs-AMTI.md`. Es un análisis de factibilidad para que la fuerza sobre el AMTI tenga una forma parecida a la GRF de marcha:

- La celda del pylon mide solo la fuerza axial. El IMU da la inclinación θ necesaria para estimar Fz.
- Hay precedentes (Aubin 2008/2012, Yang 2020) de control iterativo (ILC) ciclo a ciclo con placa de fuerza.
- **Conclusión:** es factible para la fuerza vertical. Los experimentos E0–E1 (sensado sincronizado celda + IMU + AMTI) entran en el alcance actual. E2–E5 (control) quedan por **decidir con el Dr. Elías** si entran al proyecto o quedan como trabajo futuro.

---

## Plan para la S9

**Prioridad 1: observaciones de la S7**

1. **BNO055:** aplicar el fix de inicialización del EMA, identificar y corregir el falso contacto (ya con los conectores XH del breakout) y repetir las pruebas en condiciones controladas.
2. **"Estructura del pylon":** precisar a qué componente se refiere el término y cuál es su función en el diseño.
3. **Reprogramación:** actualizar el cronograma con las actividades no ejecutadas en la S7 y la S8.
4. **Trazabilidad:** crear un registro que asocie cada cambio de hardware, firmware, filtrado o calibración con su prueba y sus archivos de datos.
5. **Repositorio:** coordinar con el Ing. Máximo León la migración de todo el proyecto al Drive de LIBRA.

**Prioridad 2: continuación**

- Revisar la PCB antes de fabricarla.
- Calibrar el offset de los ToF y definir su montaje en la plataforma.
- Integrar ToF + HX711 (+ BNO055) en un firmware único para la placa superior.

---

## Fuentes

- `Evidencias/pcb-S8/`: capturas del esquemático y la vista 3D de ambas placas.
- `Firmware/PCB_placa_superior_PINOUT.md`: pinout de la placa superior.
- `Evidencias/graficos-fuerza-S8/`: gráficos de calibración del HX711.
- `Evidencias/pruebas-fuerza-S7/entendiendo-cuentas-hx711-S7.csv`: datos de la prueba con masa patrón.
- `Firmware/test_tof/` y `Evidencias/pruebas-tof-S8/`: sketch, datos y fotos (montaje y visor en vivo) de los ToF.
- `Estado-del-arte/REFERENCIA DE POSICION ABSOLUTA/Comparativa-IMU-Bajo-Drift.md` (Secc. 7).
- `Estado-del-arte/CONTROL DE FUERZA/Control-GRF-celda-IMU-vs-AMTI.md`.

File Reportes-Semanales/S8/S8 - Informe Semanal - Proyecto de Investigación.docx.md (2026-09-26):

**INFORME SEMANAL DE AVANCE DEL PROYECTO DE INVESTIGACIÓN**

**Proyecto:** Diseño e integración de una plataforma móvil que incluya sensores para medir variables cinemáticas y cinéticas en un simulador de marcha para validar prótesis transtibiales

**Período del informe:** 19/09/2026 al 25/09/2026

**Responsable:** Alessandro Jesus Felix Tello

**1. Resumen Ejecutivo**

Semana centrada en diseño de PCB (placa superior y breakout del BNO055), calibración exitosa del sensor de fuerza con HX711, y primera prueba de los 2 sensores ToF VL53L1X. Se agregaron dos documentos de estado del arte. No se atendieron las observaciones de la S7 por una mala organización de tiempo; quedan como prioridad 1 para la S9.

**2. Actividades Realizadas**

1. **PCB de la placa superior:** esquemático y vista 3D (ESP32, IMU, HX711, alimentación, sensor Hall, 2 ToF).
2. **PCB del breakout del BNO055:** conectores XH con traba (apunta al falso contacto detectado en la S7).
3. **Calibración del HX711:** con masa patrón de 2 kg, verificada con una segunda masa — respuesta lineal y repetible.
4. **Prueba de los 2 ToF VL53L1X:** reasignación de dirección I2C confirmada en hardware (0x29/0x30); medición a 20 y 40 cm con error <10%.
5. **Estado del arte:** corrección en la comparativa de IMU (el sensor en uso desde la S6 es el BNO055, no el MPU6050) y nuevo documento sobre factibilidad de control de fuerza (celda + IMU) usando el AMTI como referencia.

**3. Actividades Planificadas vs. Actividades Ejecutadas**

| Actividad Planificada | Estado | Comentarios |
| :---- | :---- | :---- |
| Confirmar fix del bug de inicialización del EMA y repetir tanda de capturas | No ejecutada | Pasa a prioridad 1 de la S9 |
| Repetir pruebas de ruido con `ACC_RADIUS` activo | No ejecutada | Pasa a prioridad 1 de la S9 |
| Investigar conector/cable del salto de ruido (falso contacto) | No ejecutada | El nuevo breakout con conectores XH apunta a esto, sin confirmar aún |
| Calibración con masa patrón en el ADS1256 | No ejecutada | Sin avance esta semana |
| Sketch de prueba de los 2 VL53L1X con reasignación I2C | Ejecutada | — |
| *(no planificada)* PCB de la placa superior y del breakout del BNO055 | Ejecutada | — |
| *(no planificada)* Calibración del HX711 | Ejecutada | — |
| *(no planificada)* 2 documentos de estado del arte | Ejecutada | — |

**4. Dificultades o Problemas Presentados**

No se atendieron las observaciones del Dr. Elías sobre el informe de la S7 (por organización de tiempo, no por un impedimento técnico). Se corrigió un problema menor de buffer serial en los visores de ToF.

**5. Lecciones Aprendidas / Recomendaciones**

Usar conectores con traba en vez de cables sueltos ataca directamente el falso contacto detectado en la S7. Repetir el análisis de estado del arte contra el sensor real en uso (no el original) evita arrastrar una conclusión desactualizada.

**6. Actividades Planificadas para la Siguiente Semana**

| Actividad | Objetivo |
| :---- | :---- |
| Aplicar el fix del EMA, corregir el falso contacto y repetir pruebas del BNO055 | Objetivo específico 2 |
| Precisar la definición de "estructura del pylon" | Objetivo específico 1 |
| Reprogramar el cronograma con lo no ejecutado en la S7 y S8 | — |
| Crear registro de trazabilidad de pruebas | Objetivo específico 4 |
| Coordinar migración del repositorio al Drive de LIBRA | — |
| Revisar la PCB antes de fabricar | Objetivo específico 2 |
| Calibrar el offset de los ToF y definir su montaje | Objetivo específico 2 y 4 |

**7. Anexos o Evidencias**

Documento [Resumen-Semana8.md](https://github.com/ttanno/LIBRA-26-2-INSTRUMENTACION-DE-SIMULADOR-DE-MARCHA/blob/main/Reportes-Semanales/S8/Resumen-Semana8.md) (detalle técnico completo). Evidencias en [Evidencias/pcb-S8/](https://github.com/ttanno/LIBRA-26-2-INSTRUMENTACION-DE-SIMULADOR-DE-MARCHA/tree/main/Evidencias/pcb-S8), [Evidencias/graficos-fuerza-S8/](https://github.com/ttanno/LIBRA-26-2-INSTRUMENTACION-DE-SIMULADOR-DE-MARCHA/tree/main/Evidencias/graficos-fuerza-S8) y [Evidencias/pruebas-tof-S8/](https://github.com/ttanno/LIBRA-26-2-INSTRUMENTACION-DE-SIMULADOR-DE-MARCHA/tree/main/Evidencias/pruebas-tof-S8). Sketch en [Firmware/test_tof/](https://github.com/ttanno/LIBRA-26-2-INSTRUMENTACION-DE-SIMULADOR-DE-MARCHA/tree/main/Firmware/test_tof). Pinout en [PCB_placa_superior_PINOUT.md](https://github.com/ttanno/LIBRA-26-2-INSTRUMENTACION-DE-SIMULADOR-DE-MARCHA/blob/main/Firmware/PCB_placa_superior_PINOUT.md).

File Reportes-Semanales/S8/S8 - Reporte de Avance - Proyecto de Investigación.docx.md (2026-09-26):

**REPORTE DE AVANCE – PROYECTO DE INVESTIGACIÓN EN LIBRA**

| INFORMACIÓN GENERAL | |
| :---- | :---- |
| Título del Proyecto | Diseño e integración de una plataforma móvil que incluya sensores para medir variables cinemáticas y cinéticas en un simulador de marcha para validar prótesis transtibiales |
| Nombre del alumno/a | Alessandro Jesus Felix Tello |
| Nombre del asesor/a | Dante Angel Elias Giordano |
| Laboratorio de Investigación | Laboratorio de Investigación en Biomecánica y Robótica Aplicada |
| Fecha de entrega | 25/09/2026 |

**Objetivos (general y específicos) del proyecto de investigación ejecutado en LIBRA**

| Objetivo | Nivel Avance (%) |
| :---- | :---- |
| OG: Diseñar e integrar una plataforma móvil instrumentada con sensores para medir variables cinemáticas y cinéticas en un simulador de marcha, para apoyar la validación experimental de prótesis transtibiales | 34% *(propuesto — ajustar según tu criterio)* |
| OE1: Diseño Mecánico — diseñar la plataforma móvil considerando los requerimientos mecánicos y funcionales del simulador | 21% *(propuesto — ajustar según tu criterio, sin avance esta semana)* |
| OE2: Sistema Electrónico — seleccionar e integrar sensores y sistema electrónico de adquisición y procesamiento | 47% *(propuesto — ajustar según tu criterio)* |
| OE3: Software — desarrollar el software para sincronizar, visualizar, registrar y gestionar los datos del sistema | 16% *(propuesto — ajustar según tu criterio, sin avance esta semana)* |
| OE4: Validación — calibrar y validar la plataforma mediante pruebas experimentales | 15% *(propuesto — ajustar según tu criterio)* |

**Resultados del proyecto de investigación ejecutado en LIBRA**

| Resultado | Nivel Avance (%) |
| :---- | :---- |
| R1: Plataforma diseñada e integrada al simulador | 20% *(propuesto — ajustar según tu criterio)* |
| R2: Sistema de sensores (cinemáticos y cinéticos) operativo | 34% *(propuesto — ajustar según tu criterio)* |
| R3: Sistema electrónico de adquisición de datos en tiempo real | 19% *(propuesto — ajustar según tu criterio)* |
| R4: Software de monitoreo, almacenamiento y visualización | 7% *(propuesto — ajustar según tu criterio, sin avance esta semana)* |

**Síntesis de lo ejecutado durante la semana**

| Actividad | Objetivo | Descripción | Resultados |
| :---- | :---- | :---- | :---- |
| A1: PCB de la placa superior y del breakout del BNO055 | OE1/OE2 | Esquemático y vista 3D de ambas placas; conectores XH con traba en el breakout | Diseño listo, pendiente de revisión antes de fabricar |
| A2: Calibración del HX711 | OE2/OE4 | Tara + masa patrón de 2 kg, verificada con una segunda masa | Respuesta lineal y repetible confirmada |
| A3: Prueba de los 2 ToF VL53L1X | OE2/OE4 | Reasignación de dirección I2C y medición a 20/40 cm | Ambos sensores distinguen bien las distancias, error <10% |
| A4: Estado del arte (IMU y control de fuerza) | OE2 | Corrección de la comparativa de IMU; nuevo análisis de factibilidad de control con celda + IMU + AMTI | Sensor real (BNO055) documentado; factibilidad confirmada para fuerza vertical |

**Situaciones surgidas en el desarrollo del proyecto**

No se atendieron las observaciones del Dr. Elías sobre el informe de la S7, por organización de tiempo (no por un impedimento técnico); quedan como prioridad para la S9.

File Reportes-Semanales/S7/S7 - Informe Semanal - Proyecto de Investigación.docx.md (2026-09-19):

**INFORME SEMANAL DE AVANCE DEL PROYECTO DE INVESTIGACIÓN**

**Proyecto:** Diseño e integración de una plataforma móvil que incluya sensores para medir variables cinemáticas y cinéticas en un simulador de marcha para validar prótesis transtibiales

**Período del informe:** 12/09/2026 al 18/09/2026

**Responsable:** Alessandro Jesus Felix Tello

**1. Resumen Ejecutivo**

La semana se dividió entre el IMU (BNO055) y el sensor de fuerza del pylon. En el IMU se llevó el filtro EMA al firmware, se agregó un chequeo de salud de conexión, y se encontraron dos hallazgos: un bug de inicialización del filtro (arranca en 0°, transitorio de ~30 muestras) y un salto de ruido por un conector flojo. En el sensor de fuerza se hizo la primera calibración física con el HX711, en paralelo al diagnóstico del ruido del ADS1256. También se escribió el primer documento de pinout de la PCB superior. No hubo situaciones adversas, aunque los dos hallazgos del IMU siguen sin cerrar.

**2. Actividades Realizadas**

1. **Filtro EMA embebido en firmware + chequeo de salud de conexión (BNO055).** El filtro, antes solo en post-procesamiento, ahora corre en el ESP32 con corrección circular para ángulos 0°/360°, más una alerta automática si la desviación estándar de roll/pitch supera un umbral.

2. **Bug encontrado: el filtro EMA arranca en cero.** Comparando dato crudo vs. filtrado se encontró que el filtro se siembra en 0° al iniciar en vez de tomar el primer valor real, con un transitorio de ~30 muestras.

3. **Hallazgo: salto de ruido por conector flojo.** Las últimas dos tandas de un mismo día mostraron una desviación estándar muy por encima de las anteriores, lo que motivó el chequeo de salud de conexión del punto 1.

4. **Intento de completar la calibración del acelerómetro (offset + radius).** Se agregó la escritura del registro `ACC_RADIUS` — cambio experimental, pendiente de confirmar con una nueva tanda de pruebas.

5. **Primera prueba física del sensor de fuerza con el HX711.** Calibración completa (tara + masa patrón de 2 kg) con una celda real, verificada contra una segunda masa no usada en la calibración.

6. **Primer documento de diseño de PCB (pinout de la placa superior).** Arquitectura de conexionado completa: ESP32, dos sensores ToF y entrada del sensor de fuerza, con bus I2C dedicado para el BNO055 y asignación final de pines.

**3. Actividades Planificadas vs. Actividades Ejecutadas**

| Actividad Planificada | Estado (Ejecutada / En proceso / No ejecutada) | Comentarios (justificación si aplica) |
| :---- | :---- | :---- |
| Correr la calibración de acelerómetro y repetir las pruebas de ruido para confirmar la mejora | En proceso | Se agregó `ACC_RADIUS`; falta repetir la tanda de 5 pruebas de la S6 |
| Evaluar si el magnetómetro (heading) hace falta para el caso de uso del pivote | No ejecutada | El foco pasó a los dos hallazgos nuevos del filtro y la conexión |
| Imprimir la versión imprimible del bloque del pylon y correr pruebas de ajuste en el simulador | No ejecutada | El foco pasó al sensor de fuerza y al diseño de PCB |
| Evaluar agregar un sensor Hall de referencia en el punto de 0° del pivote | No ejecutada | Sin avance esta semana |
| *(no planificada)* Filtro EMA embebido en firmware + chequeo de salud de conexión | Ejecutada | Consecuencia directa de los datos de ruido de esta semana |
| *(no planificada)* Bug de inicialización del filtro y hallazgo de conector flojo | Ejecutada (diagnóstico); fix pendiente de confirmar | Encontrados al analizar las tandas del 15/09 |
| *(no planificada)* Primera prueba física del sensor de fuerza (HX711) | Ejecutada | Diagnóstico en paralelo al ruido del ADS1256 |
| *(no planificada)* Pinout de la placa superior (primer documento de PCB) | Ejecutada | Pendiente el sketch de los ToF |

**4. Dificultades o Problemas Presentados**

Dos hallazgos técnicos quedaron sin cerrar del todo: el filtro EMA arranca en 0° (transitorio de ~30 muestras), y una tanda del 15/09 mostró un salto de ruido compatible con un conector flojo, sin confirmar aún el cable/conector exacto. Ninguno bloqueó el avance de la semana, pero ambos deben confirmarse antes de tomar los próximos datos de ruido como definitivos.

**5. Lecciones Aprendidas / Recomendaciones**

Comparar crudo contra filtrado en la misma línea de datos permitió encontrar el bug de inicialización, que habría pasado desapercibido mirando solo el filtrado. Medir el ruido por tanda (en vez de un promedio único al final del día) permitió ubicar en el tiempo el cambio físico del conector. Para el sensor de fuerza, probar con un ADC distinto (HX711) sobre la misma celda separa directamente "problema del ADC/alimentación" de "problema de la celda/cableado".

**6. Actividades Planificadas para la Siguiente Semana**

| Actividad | Objetivo |
| :---- | :---- |
| Confirmar el fix del bug de inicialización del filtro EMA y repetir una tanda de capturas | Objetivo específico 2 |
| Repetir las pruebas de ruido de la S6 con la escritura de `ACC_RADIUS` activa | Objetivo específico 2 |
| Investigar el conector/cable detrás del salto de ruido del 15/09 | Objetivo específico 2 |
| Correr la misma calibración con masa patrón en el ADS1256 (misma celda, mismo cableado) para aislar el diente de sierra | Objetivo específico 2 y 4 |
| Escribir el sketch de prueba de los dos VL53L1X con reasignación de dirección I2C | Objetivo específico 2 |

**7. Anexos o Evidencias**

Documento [Resumen-Semana7.md](https://github.com/ttanno/LIBRA-26-2-INSTRUMENTACION-DE-SIMULADOR-DE-MARCHA/blob/main/Reportes-Semanales/S7/Resumen-Semana7.md) (detalle técnico completo). Imágenes y CSV en [Evidencias/pruebas-imu-S7/](https://github.com/ttanno/LIBRA-26-2-INSTRUMENTACION-DE-SIMULADOR-DE-MARCHA/tree/main/Evidencias/pruebas-imu-S7) y [Evidencias/pruebas-fuerza-S7/](https://github.com/ttanno/LIBRA-26-2-INSTRUMENTACION-DE-SIMULADOR-DE-MARCHA/tree/main/Evidencias/pruebas-fuerza-S7). Sketches en [Firmware/test_wifi_ap_bno055/](https://github.com/ttanno/LIBRA-26-2-INSTRUMENTACION-DE-SIMULADOR-DE-MARCHA/tree/main/Firmware/test_wifi_ap_bno055), [Firmware/test_hx711/](https://github.com/ttanno/LIBRA-26-2-INSTRUMENTACION-DE-SIMULADOR-DE-MARCHA/tree/main/Firmware/test_hx711) y [Firmware/test_ads1256/](https://github.com/ttanno/LIBRA-26-2-INSTRUMENTACION-DE-SIMULADOR-DE-MARCHA/tree/main/Firmware/test_ads1256). Documento de diseño en [PCB_placa_superior_PINOUT.md](https://github.com/ttanno/LIBRA-26-2-INSTRUMENTACION-DE-SIMULADOR-DE-MARCHA/blob/main/Firmware/PCB_placa_superior_PINOUT.md).

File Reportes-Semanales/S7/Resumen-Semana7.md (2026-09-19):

# Resumen de trabajo — Semana 7

**Período:** 12/09/2026 – 18/09/2026
**Responsable:** Alessandro Jesus Felix Tello

Foco de la semana: (1) IMU (BNO055) — calibración de acelerómetro, filtro embebido en firmware y dos bugs nuevos; (2) sensor de fuerza del pylon — primera prueba física con HX711, en paralelo al diagnóstico de un ruido tipo "diente de sierra" en el ADS1256, y primer documento de pinout de PCB.

**Nota:** los CSV e imágenes de esta semana estaban sueltos en `Firmware/test_wifi_ap_bno055/visor_python/` y en `Claude outputs/` (sin commitear). Se copiaron a `Evidencias/pruebas-imu-S7/` y `Evidencias/pruebas-fuerza-S7/` — falta decidir si reemplazan a los originales y comitear.

---

## 1. Sensado del IMU (BNO055)

Tandas de captura del 15/09 (14:49–17:05, ver `bno055_20260915_*.csv`) que llevaron a dos hallazgos nuevos.

### 1.1 Calibración de acelerómetro (offset + radius)

`DFRobot_BNO055` solo expone `setAxisOffset()`; el datasheet de Bosch pide también el registro `ACC_RADIUS` (0x67/0x68). Se agregó `escribirAccRadiusCrudo()` en `test_wifi_ap_bno055.ino` (~1000 mg, aproximado). **Experimental** — falta repetir las 5 pruebas de ruido de la S6 para confirmar si `calib_accel` sube a 3/3.

### 1.2 Filtro EMA embebido en firmware + chequeo de salud de conexión

El filtro EMA (antes solo en Python) ahora corre en el ESP32 (`actualizarFiltroEMA()`, alpha=0.10, corrección circular 0°/360°). Se agregó `chequearSaludConexion()`: cada ~5 s calcula std de roll/pitch crudos y alerta por Serial/UDP si supera 0.10° (umbral fijado con datos reales, ver 1.4).

### 1.3 Bug: el EMA arranca en cero

Con `comparar_filtro_ema.py` (crudo y filtrado de la misma línea del ESP32) se encontró que el EMA se siembra en 0° al arrancar, aunque el crudo ya esté estable desde la muestra 1 — el filtrado tarda ~30 muestras en converger.

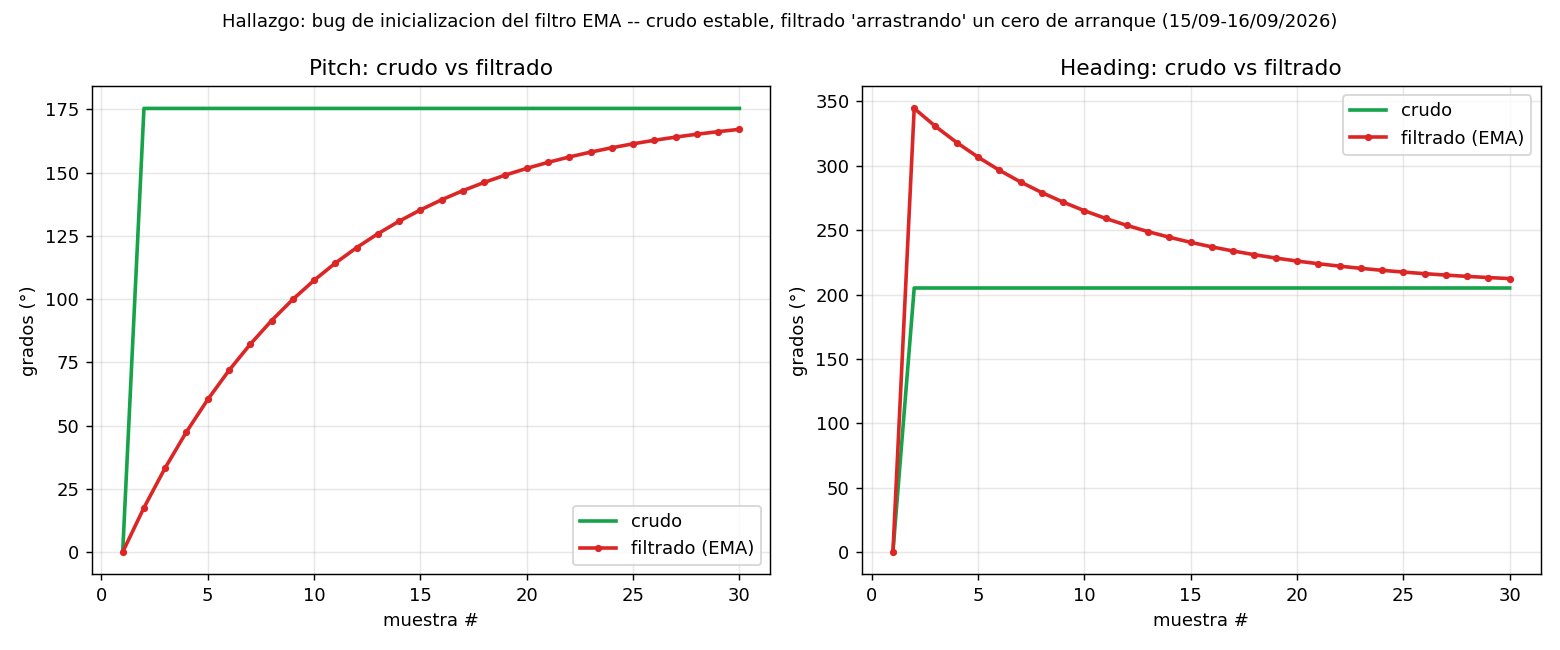
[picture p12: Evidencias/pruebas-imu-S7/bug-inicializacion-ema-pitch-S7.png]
Pitch y heading: crudo vs. filtrado, bug de inicialización del EMA
|  |
|---|
| Pitch (izq.) y heading (der.): crudo estable desde la muestra 1, filtrado arrancando en 0° — `comparacion1.csv`, 15-16/09/2026 |

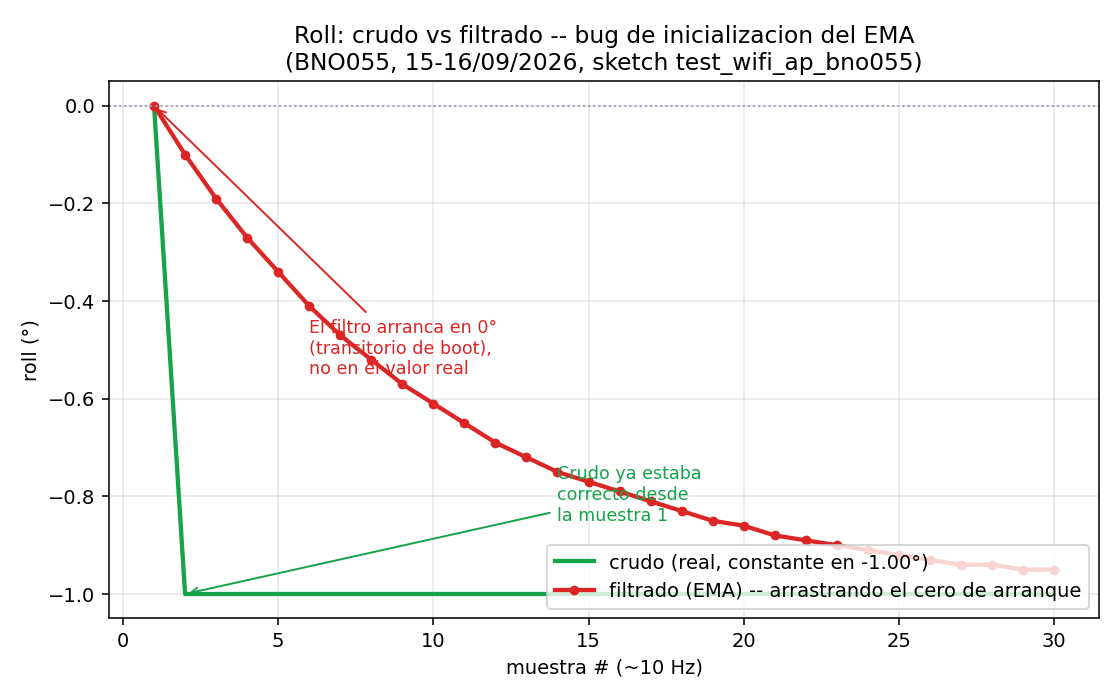
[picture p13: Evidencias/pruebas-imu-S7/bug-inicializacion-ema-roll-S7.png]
Roll: crudo vs. filtrado, detalle del bug de inicialización
|  |
|---|
| Mismo efecto en roll, a menor escala |

Fix anotado en el código (calentamiento tras `bno.begin()`), pendiente de confirmar con una nueva tanda de capturas.

### 1.4 Hallazgo: ruido alto por conector flojo

Comparando el std promedio de roll/pitch por tanda del 15/09, las últimas dos (16:50 y 17:05) salieron con std ≈0.44–0.52°, muy por encima de las anteriores y de la referencia S5/S6 (roll ≈0.31°, pitch ≈1.84° sin calibrar):

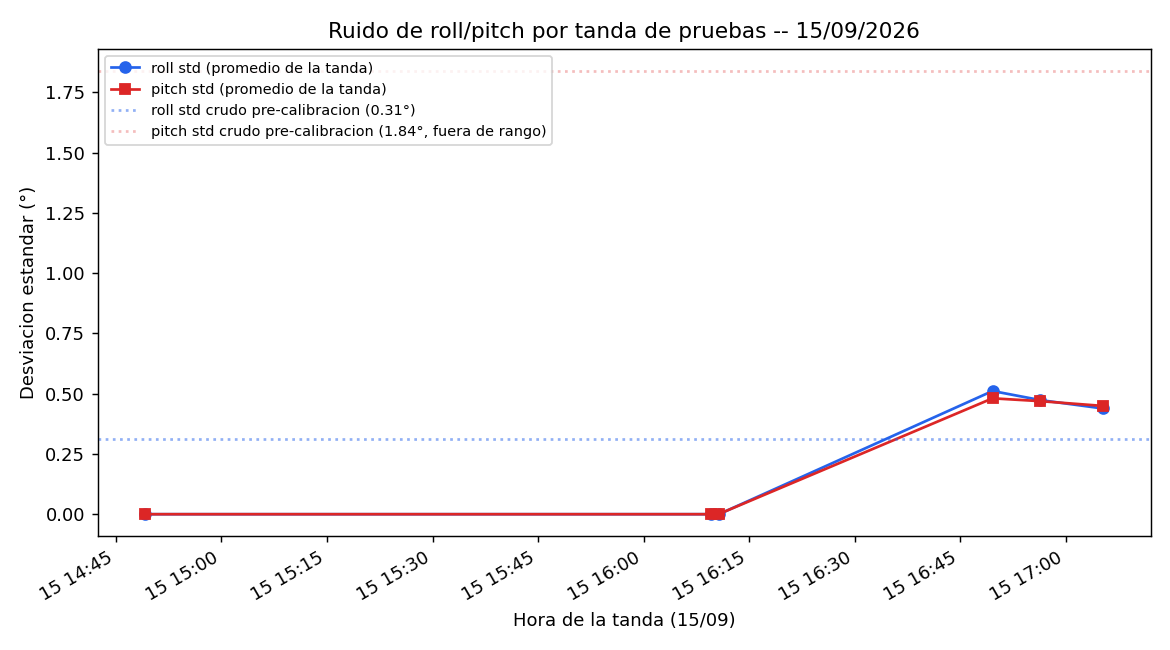
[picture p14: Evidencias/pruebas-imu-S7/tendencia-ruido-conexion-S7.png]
Tendencia de ruido roll/pitch por tanda, 15/09
|  |
|---|
| Std promedio de roll/pitch por tanda — salto de ruido en las últimas dos tandas (~16:50–17:05) |

Con conector bien puesto, std = 0.0000–0.0007°; con conector flojo, 0.35–0.63° (~500x). **Pendiente:** identificar el conector/cable exacto detrás del salto.

### 1.5 Registro a CSV: pausas automáticas

`log_csv_bno055.py` ahora acepta `--pausa <segundos>` para encadenar repeticiones sin presionar Enter (así se corrieron las tandas de 5 y 10 del 15/09), y detecta si la primera repetición salió enteramente en 0.0 (BNO055 no detectado), preguntando si continuar.

---

## 2. Sensor de fuerza del pylon: HX711 vs. ADS1256

El ADS1256 (elegido a largo plazo, 8 canales) mostraba un ruido tipo "diente de sierra" sin aislar. Se armó un sketch de prueba en paralelo con el **HX711** (`Firmware/test_hx711/`) para verificar si el problema está en la celda/cableado o en el ADS1256/alimentación.

### 2.1 Primera prueba física con masa patrón

Con el HX711 a 3.3V (evita el level shifter que sí requiere el ADS1256, de 5V fijos):

| paso | evento | raw_code | resultado |
|---|---|---|---|
| 1 | celda vacía, sin tarar | ~-22.86k (ruido ±100 cuentas) | referencia antes de tarar |
| 2 | comando `t` | — | tara guardada: -22864.8 |
| 3-4 | masa patrón 2.000 kg, `k2.0` | ~-5001.8 | factor 0.00109798 N/cuenta → **19.61 N** (≈2.000 kg) |
| 5 | celda vacía de nuevo | ~-22850 | **0.016 N** (≈0.002 kg, ~cero) |
| 5 | masa distinta (sin calibrar) | ~-13900 | **9.84 N** (≈1.004 kg, consistente) |

Detalle en `entendiendo-cuentas-hx711-S7.csv`. La masa de verificación dio un valor razonable sin recalibrar — señal de que la celda/cableado responden linealmente con el HX711. **Falta** la misma prueba con el ADS1256 para aislar si el diente de sierra es del ADC/alimentación o de la celda.

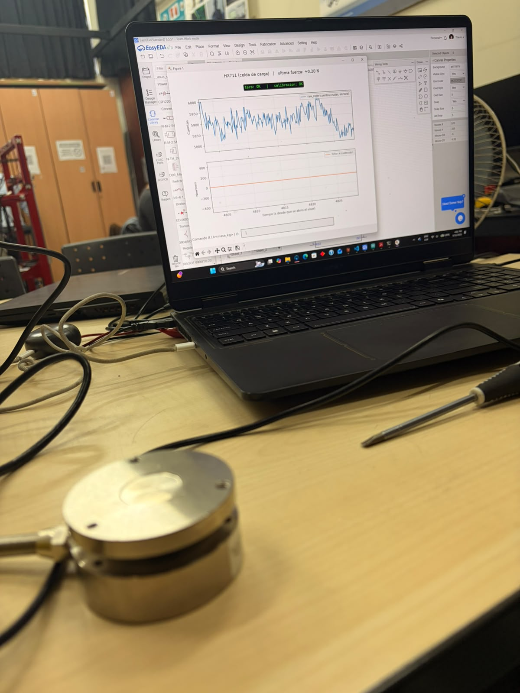
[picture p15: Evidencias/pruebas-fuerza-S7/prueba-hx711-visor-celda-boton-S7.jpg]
Prueba en vivo del HX711 con una celda de carga tipo botón; el visor Python grafica cuentas crudas y fuerza calibrada en tiempo real
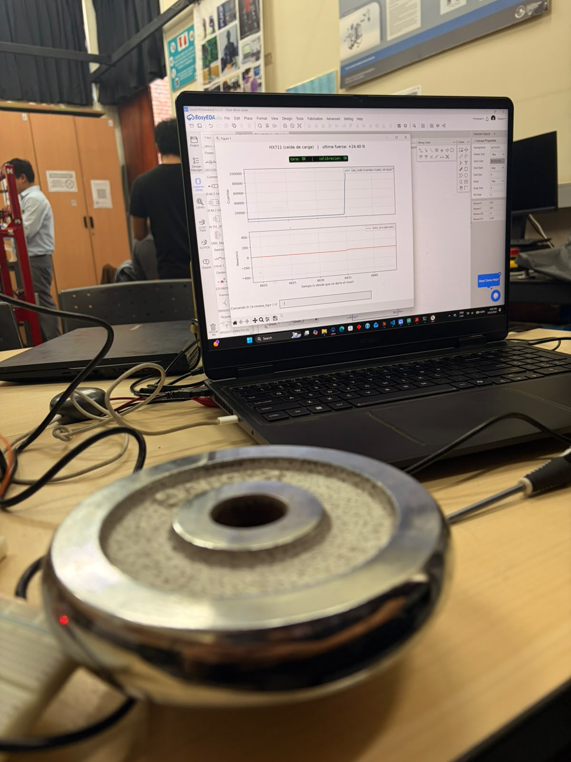
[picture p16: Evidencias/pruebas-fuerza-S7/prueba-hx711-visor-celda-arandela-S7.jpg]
Misma prueba con una segunda celda de carga tipo arandela/anillo; el salto abrupto en las cuentas crudas (de ~20 000 a ~100 000) corresponde al instante de aplicar la carga
|  |  |
|---|---|
| Celda botón — ~0.20 N sin carga | Celda arandela/anillo — salto a +24.40 N al aplicar carga |

Ambas celdas se probaron con el mismo montaje para comparar antes de decidir cuál usar en el pylon (ver `S5/Comparativa-LoadCells-S5.md`) — falta precisar cuál corresponde a cuál opción.

### 2.2 Pinout del chip HX711 (para PCB propia)

Se documentó el pinout completo del chip pelado (SOP-16L) contra el datasheet de Avia Semiconductor: regulador interno opcional, un solo pin de tierra (AGND, sin DGND), y excitación ratiométrica (EXC+ a AVDD) para cancelar ruido de alimentación.

---

## 3. Diseño de la placa superior (PCB)

Se escribió `Firmware/PCB_placa_superior_PINOUT.md`: ESP32-WROOM-32U + 2× VL53L1X + entrada HX711 arriba, BNO055 en placa aparte abajo.

- **Un solo cerebro:** todo (HX711, 2 ToF, BNO055) va al mismo ESP32.
- **Bus I2C dedicado para el BNO055** (GPIO17/SDA2, GPIO16/SCL2) — separado del bus de los ToF, que ya maneja la secuencia SHUT + reasignación de direcciones (ambos VL53L1X comparten dirección de fábrica 0x29).
- **Pines finales** evitando strapping pins y pines de solo-entrada: I2C ToF en GPIO21/22, SHUT en GPIO25/26, HX711 DT/SCK en GPIO32/33 (sin cambios de firmware).
- Pendiente: datasheet específico del módulo ToF (`MYTOF400C-VL53L1X`) y sketch de prueba de los dos VL53L1X con reasignación de dirección I2C.

---

## Próximos pasos

- Confirmar el fix del "arranque en cero" del EMA (Secc. 1.3) y repetir una tanda de capturas.
- Repetir las 5 pruebas de "sensor quieto" con `ACC_RADIUS` activo, para confirmar si `calib_accel` sube a 3/3.
- Investigar el conector/cable detrás del salto de ruido del 15/09 (Secc. 1.4).
- Correr la calibración de la Secc. 2.1 con el ADS1256 (misma celda, mismo cableado) para aislar el diente de sierra.
- Escribir el sketch de los dos VL53L1X con reasignación de dirección I2C.
- Decidir si las copias en `Evidencias/` reemplazan los archivos sueltos, y comitear.

---

## Fuentes

- `Firmware/test_wifi_ap_bno055/test_wifi_ap_bno055.ino` — filtro EMA embebido, chequeo de salud de conexión, `ACC_RADIUS`.
- `Firmware/test_wifi_ap_bno055/visor_python/comparar_filtro_ema.py` y `Evidencias/pruebas-imu-S7/comparacion1.csv` — bug de inicialización del EMA.
- `Firmware/test_wifi_ap_bno055/visor_python/bno055_20260915_*.csv` — tandas del 15/09 (Secc. 1.4).
- `Firmware/test_hx711/INSTRUCCIONES.md` y `test_hx711.ino` — driver HX711, pinout del módulo y del chip.
- `Firmware/test_ads1256/INSTRUCCIONES.md` — driver ADS1256 y contexto del diente de sierra.
- `Evidencias/pruebas-fuerza-S7/entendiendo-cuentas-hx711-S7.csv` — detalle de la calibración con masa patrón.
- `Evidencias/pruebas-fuerza-S7/prueba-hx711-visor-celda-boton-S7.jpg` y `-arandela-S7.jpg` — fotos del montaje con las dos celdas candidatas.
- `Firmware/PCB_placa_superior_PINOUT.md` — pinout completo de la placa superior.
- `Estado-del-arte/SENSORES DE FUERZA/PYLON/Comparativa-Sensores-Fuerza-Axial-Pylon.md` — comparativa que motivó el ADS1256 a largo plazo.

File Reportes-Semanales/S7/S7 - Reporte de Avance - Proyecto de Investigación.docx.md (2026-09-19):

**REPORTE DE AVANCE – PROYECTO DE INVESTIGACIÓN EN LIBRA**

| INFORMACIÓN GENERAL | |
| :---- | :---- |
| Título del Proyecto | Diseño e integración de una plataforma móvil que incluya sensores para medir variables cinemáticas y cinéticas en un simulador de marcha para validar prótesis transtibiales |
| Nombre del alumno/a | Alessandro Jesus Felix Tello |
| Nombre del asesor/a | Dante Angel Elias Giordano |
| Laboratorio de Investigación | Laboratorio de Investigación en Biomecánica y Robótica Aplicada |
| Fecha de entrega | 18/09/2026 |

**Objetivos (general y específicos) del proyecto de investigación ejecutado en LIBRA**

| Objetivo | Nivel Avance (%) |
| :---- | :---- |
| OG: Diseñar e integrar una plataforma móvil instrumentada con sensores para medir variables cinemáticas y cinéticas en un simulador de marcha, para apoyar la validación experimental de prótesis transtibiales | 31% *(propuesto — ajustar según tu criterio)* |
| OE1: Diseño Mecánico — diseñar la plataforma móvil considerando los requerimientos mecánicos y funcionales del simulador | 21% *(propuesto — ajustar según tu criterio, sin avance esta semana)* |
| OE2: Sistema Electrónico — seleccionar e integrar sensores y sistema electrónico de adquisición y procesamiento | 41% *(propuesto — ajustar según tu criterio)* |
| OE3: Software — desarrollar el software para sincronizar, visualizar, registrar y gestionar los datos del sistema | 16% *(propuesto — ajustar según tu criterio)* |
| OE4: Validación — calibrar y validar la plataforma mediante pruebas experimentales | 10% *(propuesto — ajustar según tu criterio)* |

**Resultados del proyecto de investigación ejecutado en LIBRA**

| Resultado | Nivel Avance (%) |
| :---- | :---- |
| R1: Plataforma diseñada e integrada al simulador | 18% *(propuesto — ajustar según tu criterio, sin avance esta semana)* |
| R2: Sistema de sensores (cinemáticos y cinéticos) operativo | 29% *(propuesto — ajustar según tu criterio)* |
| R3: Sistema electrónico de adquisición de datos en tiempo real | 15% *(propuesto — ajustar según tu criterio)* |
| R4: Software de monitoreo, almacenamiento y visualización | 7% *(propuesto — ajustar según tu criterio)* |

**Síntesis de lo ejecutado durante la semana**

| Actividad | Objetivo | Descripción | Resultados |
| :---- | :---- | :---- | :---- |
| A1: Filtro EMA embebido y chequeo de salud de conexión (BNO055) | OE2/OE3 | Filtro de suavizado movido de post-procesamiento a firmware, con corrección circular; chequeo automático de desviación estándar cada ~5 s con umbral basado en datos reales | Suavizado en tiempo real disponible; alerta automática ante ruido alto/conector flojo |
| A2: Bug de inicialización del filtro y hallazgo de conector flojo | OE2 | Comparación de dato crudo vs. filtrado con herramienta nueva; comparación de ruido por tanda de prueba a lo largo del día | Filtro arranca en 0° (transitorio de ~30 muestras, fix anotado en código); salto de ruido asociado a conector flojo identificado, pendiente de confirmar |
| A3: Intento de completar calibración de acelerómetro (offset + radius) | OE2/OE4 | Escritura del registro `ACC_RADIUS` (no expuesto por la librería), complemento al offset ya calibrado en la S6 | Cambio experimental aplicado; efecto sobre `calib_accel` pendiente de confirmar con nueva tanda de pruebas |
| A4: Primera prueba física del sensor de fuerza (HX711) | OE2/OE4 | Driver de prueba en paralelo al ADS1256 (que muestra ruido tipo diente de sierra); calibración con tara + masa patrón de 2 kg, verificada con una segunda masa | Calibración funcional y consistente con las masas de prueba; sirve de diagnóstico para aislar el problema del ADS1256 |
| A5: Pinout de la placa superior (primer documento de PCB) | OE1/OE2 | Arquitectura de conexionado completa: ESP32 + 2 sensores ToF + entrada del sensor de fuerza, con bus I2C dedicado para el BNO055 en placa aparte | Asignación de pines definida, evitando pines críticos de arranque del ESP32; falta el sketch de prueba de los ToF |

**Situaciones surgidas en el desarrollo del proyecto**

No se presentaron situaciones adversas que bloquearan el avance. Quedan dos hallazgos técnicos sin cerrar del todo: el bug de inicialización del filtro EMA (fix anotado en el código, sin confirmar con una nueva prueba) y el salto de ruido asociado a un conector flojo del BNO055 (sin identificar el cable/conector específico todavía).

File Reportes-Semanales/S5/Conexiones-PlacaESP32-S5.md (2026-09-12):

# Conexiones — Placa del ESP32 (hub de sensores), Semana 5

**Fecha:** 10/09/2026
**Contexto:** avance sobre el pendiente de diseño mecánico/electrónico de la S5 (`Reportes-Semanales/S5/Pendientes.md`). Esta nota define el conexionado eléctrico propuesto para la placa que centraliza el ESP32, con el ADS1256 y las entradas de los demás sensores (IMU, distancia, ángulo, fuerza) como "salidas" hacia el resto del sistema. Es un punto de partida para el ruteo físico (protoboard/PCB), no un cierre — hay decisiones pendientes marcadas explícitamente abajo.

---

## 1. Pines que el firmware actual ya fija (no mover sin actualizar los `.ino`)

| Función | Pin(es) ESP32 | Fuente |
|---|---|---|
| I2C (SDA / SCL) | GPIO21 / GPIO22 | `test_bno055.ino`, `test_mpu6050.ino`, `homing_absoluto.ino` |
| Driver del husillo — STEP | GPIO26 | `homing_husillo_hall.ino` |
| Driver del husillo — DIR | GPIO27 | `homing_husillo_hall.ino` |
| Driver del husillo — ENABLE (activo en bajo) | GPIO25 | `homing_husillo_hall.ino` |
| Sensor Hall (homing husillo) — entrada con pull-up | GPIO34 | `homing_husillo_hall.ino` |

Estos seis pines quedan fijos tal como están; el resto de la placa se diseña alrededor de ellos.

## 2. Bus SPI propuesto — ADS1256 (ADC de la celda de carga / AMTI)

Aún no hay pines de SPI asignados en ningún `.ino`. Propuesta usando el bus VSPI por defecto del ESP32 (no choca con los pines de la sección 1):

| Señal ADS1256 | Pin ESP32 | Nota |
|---|---|---|
| SCK | GPIO18 | VSPI por defecto |
| MISO (DOUT) | GPIO19 | VSPI por defecto |
| MOSI (DIN) | GPIO23 | VSPI por defecto |
| CS (SYNC/CS) | GPIO5 | Pin de strapping del ESP32 — no debe quedar forzado a nivel bajo durante el arranque; usar resistencia pull-up externa de 10 kΩ si se observan resets raros |
| DRDY | GPIO4 | Entrada, idealmente con interrupción (`attachInterrupt`) para no hacer polling |
| RESET / PDWN | 3V3 (fijo) | La mayoría de módulos ADS1256 ya traen estos pines a nivel alto en la propia placa — verificar en el módulo Teyleten Robot comprado antes de cablear un GPIO extra para esto |

**Entradas analógicas del ADS1256 (8 canales / 4 pares diferenciales):**

- **AIN0/AIN1 (diferencial):** celda de carga (puente de Wheatstone) — *pendiente confirmar con el vendedor si la salida es realmente mV/V cruda; si resulta ser "Push-Pull" como advierte `Comparativa-LoadCells-S5.md`, este par no sirve tal cual y hay que revisar acondicionamiento antes de cablear.*
- **AIN2..AIN7:** libres por ahora. **La integración de los 6 canales de la AMTI con el ADS1256 queda despriorizada por decisión del 10/09** (no descartada) hasta cerrar la celda de carga del pylon y el VL53L1X. Cuando se retome, sigue habiendo el mismo problema de fondo ya identificado: con solo 4 pares diferenciales en el chip, 6 canales AMTI + 1 de la celda no caben todos en modo diferencial — faltará decidir single-ended (si la AMTI está referenciada a tierra común, según el modo MSA-6 Compatible vs. Fully Conditioned, aún sin confirmar) vs. un segundo ADC/mux.

## 3. Bus I2C compartido — IMU y sensor de ángulo

Todo lo que sea I2C comparte GPIO21 (SDA) / GPIO22 (SCL) ya fijados:

| Dispositivo | Dirección I2C típica | Estado |
|---|---|---|
| MPU6050 (actual) | 0x68 (AD0→GND) | En uso hoy |
| LSM6DSR (candidato reemplazo Nivel A) | 0x6A / 0x6B (según SDO) | Pendiente de decisión (`Comparativa-IMU-Bajo-Drift.md`) |
| ICM-45686 (candidato reemplazo Nivel A) | 0x68 / 0x69 (según AP_AD0) | Mismo pendiente — **si se elige este y se mantiene el MPU6050 en la placa a la vez, hay que fijar direcciones distintas (AD0/AP_AD0) para no chocar** |
| BNO055 (pruebas) | 0x28 (COM3→GND) / 0x29 (COM3→3V3) | Solo pruebas de banco por ahora — confirmar si queda en la placa final o si el proyecto se queda con un único IMU. **Si el módulo es el DFRobot SEN0374 (Fermion BNO055), ver nota 3.1 abajo** |
| AS5600 (ángulo, BOM sin cerrar) | 0x36 (fija, no configurable) | Sensor final de rotación aún sin elegir en firme (`Pendientes.md` S5, sección BOM) |

**Punto a vigilar (resuelto en la sección 4):** BNO055 (dirección 0x29 si se puentea) y VL53L1X (dirección de fábrica también 0x29) chocarían en el mismo bus si ambos quedan en 0x29 — la decisión del 10/09 es dejar el BNO055 en 0x28 (default) para evitar el choque sin tocar el XSHUT del VL53L1X.

### 3.1 Módulo DFRobot SEN0374 (Fermion BNO055) — según el esquemático subido

El esquemático que compartiste (`SEN0374_bno055intelligent9axissensor_schematics_v1.pdf`) confirma que **no es el chip BNO055 pelado**, sino un módulo con acondicionamiento propio, lo que simplifica bastante la placa del ESP32:

- **Regulador propio (U2, ME6206A30M3G):** el módulo acepta una alimentación VCC (típicamente 5 V) y la regula internamente a 3.3 V para el chip — no hace falta que la placa del ESP32 le entregue 3.3 V regulado aparte, con 5 V a su VCC alcanza.
- **Level-shifting de I2C integrado (Q1/Q2, 2N7002):** SDA/SCL salen del conector ya desplazados de nivel entre el dominio interno de 3.3 V del BNO055 y el VCC del conector — es decir, el módulo se puede conectar directo al bus I2C del ESP32 (3.3 V) sin resistencias de pull-up adicionales de tu parte; el módulo ya trae las suyas (R14–R17, 10 kΩ).
- **Pad I2C_ADDR seleccionable:** hay un puente/pad dedicado para elegir entre las dos direcciones I2C del BNO055 (0x28 por defecto / 0x29). Esto es justo lo que resuelve el conflicto con el VL53L1X mencionado arriba — si terminas usando este módulo junto con un VL53L1X, puedes dejar el BNO055 en 0x28 sin tocar el firmware de dirección del VL53L1X.
- **Pines de P2 (RST, BL_IND, PS2, PS1, nBOOT):** están para modo de programación/bootloader del propio módulo y ya tienen sus resistencias de pull-up/pull-down correctas en la placa (R2–R4, R9) para arrancar en modo normal — **no es necesario cablearlos al ESP32**, solo quedan expuestos por si algún día se necesita reprogramar el módulo directamente.
- **Conexión mínima real a la placa del ESP32:** VCC, GND, SDA→GPIO21, SCL→GPIO22, y opcionalmente INT si se quiere usar la interrupción de datos del BNO055 en vez de hacer polling (dejarlo en un GPIO libre, p. ej. GPIO33, si se decide usarlo).
- **Confirmado con la librería `DFRobot_BNO055` y el datasheet Bosch (rev 1.4) que subiste:** el chip solo expone I2C y UART a nivel de hardware (no SPI), y la librería de DFRobot solo implementa la clase I2C (`DFRobot_BNO055_IIC`, dirección por defecto `0x28`) — coherente con dejarlo en el mismo bus I2C de la sección 3 y no reservarle pines de SPI. Si se usa el pin INT con esta librería en el ESP32, el ejemplo `interrupt.ino` de DFRobot usa la sintaxis vieja de Arduino Uno (`attachInterrupt(0, ...)`); en ESP32 hay que cambiarla por `attachInterrupt(digitalPinToInterrupt(PIN), ...)` con el GPIO real.

## 4. Sensor de distancia — VL53L1X (decidido 10/09)

Cerrado: **VL53L1X** (I2C), no TF-Luna — coherente con el adaptador que ya se está diseñando en Fusion 360 (`Evidencias/diseno-adaptador-sensor-S5/`). Va en el bus I2C compartido de la sección 3, dirección de fábrica 0x29.

**Punto a resolver junto con esta decisión:** el BNO055 (sección 3.1) puede configurarse en esa misma dirección 0x29 (COM3→3V3) — para que no choquen, dejar el BNO055 en su dirección **por defecto 0x28** (pad I2C_ADDR del módulo sin puentear). Así no hace falta ni cablear el XSHUT del VL53L1X para este caso puntual; ese GPIO (sección 3, ej. GPIO32) queda como opción solo si más adelante se agrega un segundo dispositivo en 0x29.

El GPIO16/17 que se había reservado para TF-Luna (UART2) queda libre — ya no se necesita.

## 5. Alimentación y tierra

- Riel de 3.3 V para IMU, AS5600, y lógica del ADS1256 (según el módulo).
- Riel de 5 V (o el que pida el puente de la celda de carga como excitación — verificar en la ficha una vez confirmado el proveedor) para la excitación del puente de Wheatstone.
- Referencia de tierra común entre ESP32, ADS1256 y la celda de carga — al ser la parte más sensible a ruido de la placa (24 bits de resolución), conviene mantenerla separada de la tierra de potencia del driver del husillo (STEP/DIR/ENABLE) y unirlas en un solo punto (tierra en estrella) en vez de un plano compartido sin cuidado.

## 6. Resumen de pines libres usados en esta propuesta

GPIO4, 5, 18, 19, 23 (y 32 si más adelante se necesita XSHUT para un segundo dispositivo en 0x29, y 33 si se usa el INT del BNO055). Todos libres respecto a lo que ya usan los `.ino` actuales (21, 22, 25, 26, 27, 34). GPIO16/17 quedan libres — ya no se reservan para TF-Luna (descartado, ver sección 4).

---

## Pendiente antes de cerrar el diseño de la placa

- [ ] Confirmar con el vendedor el tipo de salida real de la celda de carga (mV/V vs. Push-Pull) — bloquea el cableado de AIN0/AIN1.
- [ ] Interfaz de los 6 canales de la AMTI con el ADS1256 — **despriorizada por decisión del 10/09**, retomar más adelante (single-ended vs. mux adicional sigue siendo la pregunta de fondo cuando se retome).
- [ ] Decidir el reemplazo de IMU (LSM6DSR vs. ICM-45686 vs. mantener MPU6050) y si el BNO055 queda o no en la placa final.
- [x] Sensor de distancia del BOM: **VL53L1X** (decidido 10/09) — bus I2C compartido, ver sección 4.

## Fuentes

- `Firmware/test_bno055/test_bno055.ino`, `Firmware/test_mpu6050/test_mpu6050.ino`, `Firmware/homing_absoluto/homing_absoluto.ino`, `Firmware/homing_husillo_hall/homing_husillo_hall.ino` — pines ya fijados en firmware.
- `Reportes-Semanales/S5/Comparativa-LoadCells-S5.md` — ADS1256 decidido, alerta de salida "Push-Pull" de la celda candidata #4.
- `Estado-del-arte/REFERENCIA DE POSICION ABSOLUTA/Comparativa-IMU-Bajo-Drift.md` — candidatos de reemplazo de IMU.
- `Reportes-Semanales/S4/Pendientes.md`, `Reportes-Semanales/S5/Pendientes.md` — pendientes heredados de interfaz AMTI/ADS1256 y BOM de sensores.
- `SEN0374_bno055intelligent9axissensor_schematics_v1.pdf` (DFRobot, esquemático del módulo Fermion BNO055) — confirma regulador y level-shifting integrados, y el pad de selección de dirección I2C.
- `SEN0374_bno055intelligent9axissensor_datasheet_v1.pdf` (Bosch, datasheet BNO055 rev 1.4) — confirma interfaces I2C/UART (sin SPI) y rangos de VDD/VDDIO.
- `SEN0374_bno055intelligent9axissensor_library_v1.zip` (librería Arduino `DFRobot_BNO055`) — confirma que solo implementa I2C (dirección `0x28` por defecto) y el patrón de uso de la interrupción.

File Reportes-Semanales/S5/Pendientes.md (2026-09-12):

# Pendientes — Semana 5 (abierto 29/08/2026)

Nota de trabajo informal (no es parte de los reportes formales). Continúa el mismo formato de `Reportes-Semanales/S4/Pendientes.md`, que quedó cerrado como histórico — retoma lo que seguía abierto de la S4 y suma lo nuevo de la S5 (compra del sensor de fuerza, comparativa de IMU de bajo drift, diseño del pylon en dos versiones).

## Selección de sensor de fuerza del pylon (foco de esta semana)

- [x] Comparativa de celdas de carga y electrónica de Amazon documentada (`Comparativa-LoadCells-S5.md`).
- [x] Celda de carga comprada: opción #4 (fuelle, patrón 3×M4), variante 220 lb (~978 N) — dimensionada para el caso de carga puntual ~1200 N (S3), no para el ensayo P5 completo.
- [ ] Escribir al vendedor para confirmar tipo de salida real (mV/V crudo vs. "Push-Pull") y compatibilidad con el ADS1256.
- [x] Disponibilidad del ADS1256 confirmada como comprable con envío a Perú (~US$27).

## Diseño mecánico del pylon (avance esta semana)

- [x] Versión A del bloque superior diseñada, con patrón de agujeros dimensionado para el sensor comprado.
- [x] Versión B (imprimible, con insertos roscados + tornillos como referencia mecánica temporal) diseñada, para no bloquear pruebas del simulador.
- [x] Guardar las 4 imágenes del diseño en `Evidencias/diseno-pylon-S5/` y activar los enlaces del resumen.
- [ ] Imprimir la versión B y correr pruebas de ajuste/ensamblaje en el simulador.
- [ ] Validación estructural en Fusion 360 (Static Stress Simulation) de la versión A, una vez confirmada la capacidad final del sensor — sigue abierto desde la S1.
- [ ] Caso de carga puntual ~1200 N (observación de la S3, 26/08) — sigue sin correr.

## IMU de bajo drift (avance esta semana)

- [x] Comparativa de IMU de bajo drift documentada (`Comparativa-IMU-Bajo-Drift.md`), incluyendo diagnóstico de las 3 causas posibles del problema de repetibilidad del homing.
- [ ] Decidir y comprar el reemplazo de Nivel A (LSM6DSR o ICM-45686) para el MPU6050 actual.
- [ ] Diseñar una marca/tope mecánico de referencia para el pivote (combinar con el IMU, no reemplazarlo).
- [ ] Repetir la validación cuantitativa del homing (heredado de la S4) una vez cambiado el IMU y/o agregado el tope mecánico.

## Pruebas de IMU (BNO055 y MPU6050)

- [x] **Primera prueba "dejarlo quieto" corrida (10/09, 30 s, ver `Evidencias/pruebas-imu-S5/`):** roll std ≈0.31°, pitch std ≈1.84° (más ruidoso que roll), heading con wrap-around en 0°/360° (no analizable con desviación estándar lineal, hace falta estadística circular).
- [ ] **BUG encontrado (10/09):** durante toda esa prueba `calib_sys/gyro/accel/mag` salió en `0,0,0,0` — ni siquiera el giroscopio calibró estando quieto, lo cual es raro. Revisar si `getCalStatus()` está leyendo bien el registro o si el sensor de verdad no está calibrado (correr la rutina de calibración: figura de 8 para el magnetómetro, varias orientaciones para el acelerómetro) antes de confiar en los números de ruido.
- [ ] **BUG encontrado (10/09):** una segunda prueba de 30 s salió con **las 287 filas en exactamente 0.000** en las 10 columnas — no es ruido real, algo falló (posiblemente ligado al comando de borrar cero que el script manda al iniciar). Repetir mirando el Monitor Serie en vivo para confirmar si el ESP32 se cuelga o hay un bug en el manejo del comando 'c'. Archivo no usable para análisis (`bno055_20260910_162052.csv`).
- [x] **Decisión de filtrado (10/09):** empezar con un filtro simple (promedio móvil exponencial / EMA) en vez de machine learning — el ruido observado es instrumental (gaussiano, sin patrón) y el BNO055 ya hace fusión tipo Kalman internamente (modo NDOF), así que ML estaría sobre-dimensionado. Con los datos de la Prueba 1, EMA alpha=0.05 bajó el std de pitch de 1.84° a 1.16° (ver `Evidencias/pruebas-imu-S5/filtro-ema-comparacion-pitch-S5.png`). Pendiente: no tiene sentido optimizar el filtro hasta resolver el bug de calibración de arriba.
- [ ] Prueba lado a lado BNO055 vs. MPU6050 sobre el mismo movimiento.
- [ ] Confirmar el MPU6050 (o su reemplazo Nivel A) contra el inventario del laboratorio.

## Referencia de posición absoluta — husillo (heredado, sin avance esta semana)

- [ ] Medir el diámetro real del eje del motor (calibre) y diseñar/imprimir el collarín con el imán de neodimio.
- [ ] Montar el sensor Hall + collarín y validar el homing en el motor real.
- [ ] Definir y combinar con un límite físico de fin de carrera del riel (switch mecánico/óptico/Hall).

## Referencia de posición absoluta — pivote (flexo-extensión) (nuevo, 10/09)

- [x] **Diagnóstico (10/09):** el motor paso a paso del pivote es lazo abierto puro (sin encoder) — parte de -65°, cuenta pasos hasta +65°, e infiere el 0° a partir de ese conteo. Si el motor pierde pasos bajo carga (justo cuando la prótesis pisa/carga el sistema — el momento más importante del ensayo), el conteo se desfasa respecto al ángulo real, y el pivote ya no vuelve al 0° real al terminar la prueba aunque el conteo diga que sí. Es la razón de fondo de por qué no basta con contar pasos y de por qué ya existe `homing_absoluto.ino` (el IMU mide inclinación real respecto a la gravedad, no depende del conteo de pasos).
- [ ] Evaluar agregar un **sensor Hall + imán en el punto de 0° (horizontal) del pivote**, análogo a `homing_husillo_hall.ino` en el husillo — daría un evento físico de referencia independiente del conteo de pasos, para re-calibrar el cero con confianza entre pruebas. Limitación: no corrige el desfase a mitad de un ciclo de marcha, solo permite volver a 0° real de forma confiable al reiniciar/re-homear.
- [ ] Confirmar si el IMU (actual o su reemplazo de bajo drift, ver sección "IMU de bajo drift") es suficiente por sí solo para detectar el desfase en tiempo real durante el ensayo, o si conviene combinarlo con el Hall del punto anterior — mismo patrón ya identificado en `Arquitecturas-Referencia-Absoluta-sin-Goniometro.md` (todo sistema repetible usa un evento físico fijo, no solo un sensor).
- Relacionado: el ángulo real de los dos limit switches del pivote tampoco está confirmado al 100% todavía (ver sección AMTI más abajo, heredado ahí por organización del documento, no porque sea parte de la AMTI).

## Sensores de distancia y ángulo — heredado, cerrar BOM

- [x] Sensor de traslación decidido (10/09): **VL53L1X** (I2C), no TF-Luna — coherente con el adaptador que ya se está diseñando en Fusion 360 (`Evidencias/diseno-adaptador-sensor-S5/`, ver `Resumen-Semana5.md` sección 4). `Conexiones-PlacaESP32-S5.md` actualizado en consecuencia.
- [ ] Sensor de rotación (AS5600) sigue sin cerrar.
- [ ] Cerrar el BOM completo de sensores.

## Mecanismo de elevación — espesor de la plataforma superior (nuevo, 08/09)

- [ ] Medir cuánta distancia se levanta el mecanismo (carrera del actuador/husillo entre la plataforma inferior y la superior) para determinar el espesor necesario de la plataforma de arriba.

## Heredado de la S1 — bibliografía (sigue abierto)

- [ ] [2] Confirmar autor/año exacto de la tesis de maestría (R. Davis, Cleveland State Univ.) contra OhioLINK — accession `csu1396786747`.
- [ ] [4] Nie et al. — documento IEEE no indexado en las búsquedas realizadas; requiere acceso directo a IEEE Xplore.
- [ ] [12] "Evaluating shear and normal force with the use of an instrumented transtibial socket" — sin autor identificado.
- [ ] [15] "Instrumented socket inserts for sensing interaction at the limb-socket interface" — sin autor identificado.
- [ ] P3 y P6 de ISO 10328 sin verificación confiable — no priorizar salvo que el proyecto deba cubrir usuarios >100 kg.
- [ ] Decidir el alcance de sensores de presión distribuida (FSR array) vs. solo celda de carga puntual, y ajustar la Secc. 6 de la revisión bibliográfica en consecuencia.
- [ ] Actualizar Secc. 4.1, 9 y 10 de la revisión bibliográfica con el cambio de prioridad GRF/pylon y la arquitectura de sensores por DOF (pendiente desde la S2).

## Heredado de la S1/S2/S3 — plataforma AMTI (despriorizada por ahora, 10/09)

**Decisión (10/09):** el foco de electrónica pasa a cerrar la celda de carga del pylon + el VL53L1X; la integración de la AMTI con el ADS1256 queda en pausa (no descartada, solo sin trabajo activo por ahora). Los puntos de abajo siguen abiertos tal cual.

- [x] Modo de salida analógica del amplificador confirmado (10/09): **Fully Conditioned** (no MSA-6 Compatible).
- [ ] Ubicar el certificado de calibración real de la plataforma (matriz de sensibilidad real, no la de ejemplo del manual) — con el amplificador en Fully Conditioned, la matriz de sensibilidad convierte volts ya acondicionados (ganancia+offset aplicados por el amplificador) directo a fuerza/momento, a diferencia de MSA-6 Compatible; confirmar que el certificado que se ubique corresponda a este modo.
- [ ] Seguimiento del formulario de soporte técnico enviado a AMTI — sigue sin respuesta (confirmado 10/09).
- [ ] Diseñar la interfaz de lectura de los 6 canales de la AMTI con el ADS1256.
- [x] Confirmado (10/09): el motor paso a paso del pivote (flexo-extensión) **no tiene encoder real** — la posición se deriva por conteo de pasos en lazo abierto respecto a los pasos que debe dar el motor. Tiene **dos limit switches en ángulos supuestamente conocidos**, pero **el ángulo absoluto de esos switches todavía NO está confirmado al 100%** — son un punto de referencia física candidato, no una referencia ya validada. Relevante para `Estado-del-arte/REFERENCIA DE POSICION ABSOLUTA/Arquitecturas-Referencia-Absoluta-sin-Goniometro.md` y el problema de repetibilidad del homing por IMU (`homing_absoluto.ino`, S4/S5).
- [ ] Medir/verificar el ángulo real de al menos uno de los dos limit switches (ej. con el mismo IMU ya montado, o un goniómetro externo, en el momento en que el switch se activa) antes de poder usarlos como referencia absoluta confiable para el homing del pivote.

## Sin dueño claro — verificar antes de cerrar la semana

- [ ] Confirmación formal del asesor sobre el simulador existente (transtibial únicamente, estructura ya construida) — sigue informal desde la S1.

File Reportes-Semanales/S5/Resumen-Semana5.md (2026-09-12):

# Resumen de trabajo — Semana 5

**Período:** 29/08/2026 – 04/09/2026
**Responsable:** Alessandro Jesus Felix Tello

Resumen narrativo de la semana, complementario a `Comparativa-LoadCells-S5.md` (mismo directorio) y al resumen de la semana anterior (`S4/Resumen-Semana4.md`).

El foco de la semana estuvo en cerrar el pendiente heredado de la S4 de selección de sensor de fuerza del pylon (comparativa de celdas de carga disponibles en Amazon y compra de la elegida), en evaluar alternativas de IMU de menor drift a partir del problema de repetibilidad del homing detectado al usar `homing_absoluto.ino`, y en avanzar el diseño mecánico del bloque superior del pylon en dos versiones paralelas: una dimensionada para el sensor de fuerza ya comprado, y una versión simplificada e imprimible de inmediato para no bloquear las pruebas de ajuste en el simulador mientras se espera la pieza física.

---

## 1. Selección y compra del sensor de fuerza del pylon

`Comparativa-LoadCells-S5.md` compara 4 celdas de carga y 2 módulos de electrónica de lectura encontrados en Amazon contra los requisitos ya fijados en la comparativa de la S4 (`Estado-del-arte/SENSORES DE FUERZA/PYLON/Comparativa-Sensores-Fuerza-Axial-Pylon.md`): fuerza de prueba P5 = 2240 N, fuerza última P5 = 4480 N, margen objetivo ~1.5–2× sobre la última, e interfaz mecánica de placa plana atornillada (no adaptador tipo pyramid).

De las cuatro celdas comparadas, la candidata **#4** (tipo fuelle, Ø2.283 in, con patrón de pernos 3×M4 documentado en la ficha) fue la que se terminó comprando — es la única opción con el patrón de pernos confirmado explícitamente, lo que evita depender de una interfaz no verificada. La variante de capacidad elegida fue **220 lb** (~978 N), menor que la de 2200 lb que la comparativa señalaba como la que cumple el margen objetivo sobre la carga última P5 (4480 N) — esto es intencional: la celda se dimensionó para el caso de carga puntual de **~1200 N** (observación de la S3, 26/08, sección "Diseño mecánico del pylon" de `S4/Pendientes.md`), no para el ensayo P5 completo, que sigue siendo un caso de carga distinto y no priorizado por ahora.

También quedó confirmada la disponibilidad del ADS1256 (Teyleten Robot, ~US$27 con envío) como electrónica de lectura, cerrando la parte de "verificar disponibilidad" del pendiente heredado de la S4 — ver detalle completo en `Comparativa-LoadCells-S5.md`, secciones 3 y 4.

---

## 2. Comparativa de IMU de bajo drift para el homing del pivote

Al usar el homing por acelerómetro (`Firmware/homing_absoluto/homing_absoluto.ino`, prototipado en la S4) se observó que, al fijar el cero del pivote y volver físicamente a esa misma posición más tarde, el ángulo reportado por el MPU6050 no coincide exactamente con el cero guardado. `Estado-del-arte/REFERENCIA DE POSICION ABSOLUTA/Comparativa-IMU-Bajo-Drift.md` documenta el diagnóstico y la comparativa de alternativas, incluyendo IMU de grado "espacial/aeroespacial" a pedido explícito, para calibrar expectativas de costo.

**Diagnóstico:** el problema tiene tres causas posibles y no todas se resuelven comprando mejor IMU — (1) bias sistemático de fábrica del acelerómetro del MPU6050, que el sobremuestreo de la S4 no corrige (solo reduce ruido aleatorio, no bias); (2) deriva del giroscopio si hay integración entre eventos; (3) holgura mecánica real del pivote, que ningún sensor corrige. La causa 1 se identifica como la más probable en este caso puntual, porque el homing es una lectura estática de inclinación, no una integración continua.

**Comparativa por nivel:**
- **Nivel A (reemplazo directo, mismo bus I2C, unos pocos dólares):** LSM6DSR o ICM-45686 — según datos de la comunidad SlimeVR, el MPU6050 actual es el peor de la lista para este problema (drift perceptible en 1–5 min), mientras que ICM-45686 tarda 45–60 min.
- **Nivel B (industrial/táctico, US$300–600):** VectorNav VN-100, Xsens MTi-3 o Analog ADIS16470 — calibración de fábrica multi-temperatura y EKF integrado; el VN-100 publica 0.5° RMS de exactitud estática de roll/pitch, directamente relevante para el homing.
- **Nivel C (grado espacial/navegación, FOG/RLG, US$10 000–200 000+):** mencionado solo como referencia a pedido — resuelve un problema distinto (navegación autónoma sin referencia externa) y es sobre-ingeniería para este caso.

**Recomendación aplicada a LIBRA:** cambiar el MPU6050 por un LSM6DSR o ICM-45686 (Nivel A) como mejora inmediata de bajo costo, y combinarlo con una marca/tope mecánico físico de referencia en el pivote — la solución más barata y coherente con el patrón ya identificado en la S4 (`Arquitecturas-Referencia-Absoluta-sin-Goniometro.md`: todo sistema repetible usa un evento físico fijo, no solo un sensor). El Nivel B queda como opción si el presupuesto lo permite más adelante; el Nivel C se descarta explícitamente por costo y por resolver un problema que LIBRA no tiene.

---

## 3. Diseño mecánico del bloque superior del pylon — dos versiones en paralelo

Se avanzó el diseño del bloque que aloja el sensor de fuerza sobre el cono de transición del pylon, en dos versiones que comparten la misma huella general (placa superior redondeada + placa intermedia, ambas con esquinas redondeadas, apoyadas sobre la transición cónica hacia el resto del pylon):

**Versión A — con el sensor de fuerza ya comprado:**

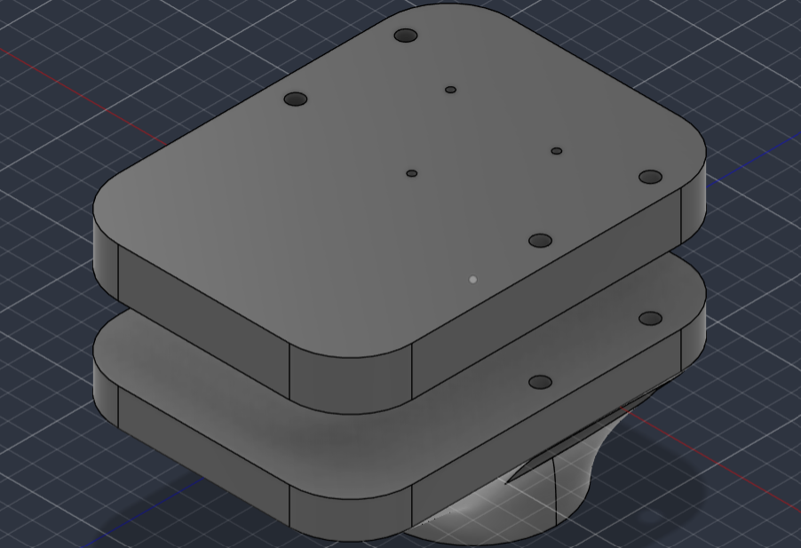
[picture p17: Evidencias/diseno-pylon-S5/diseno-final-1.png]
Diseño final — vista 1
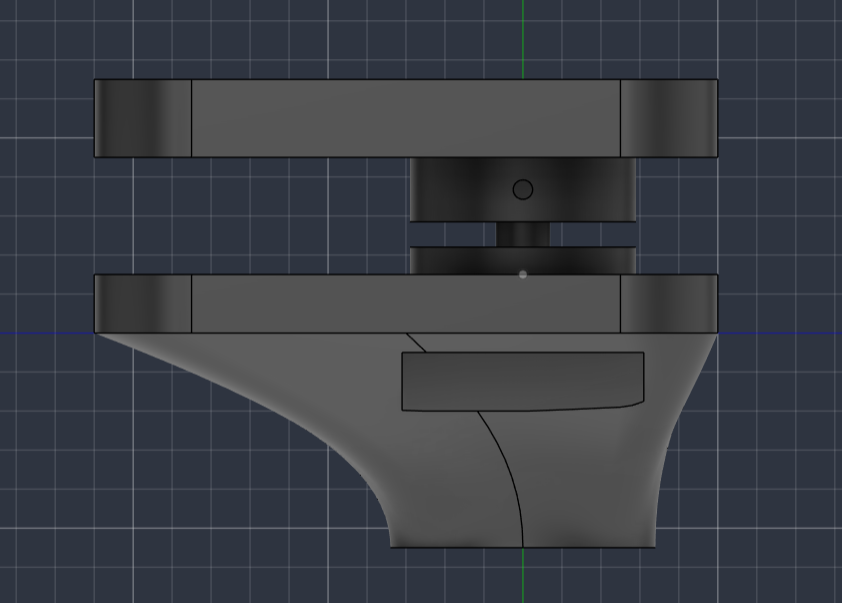
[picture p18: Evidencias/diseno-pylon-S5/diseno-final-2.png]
Diseño final — vista 2
|  |  |
|---|---|
| Vista isométrica del bloque superior con el patrón de agujeros dimensionado para el sensor comprado | Segunda vista isométrica del mismo diseño |

La placa superior tiene el patrón de agujeros dimensionado para la celda #4 comprada (agujeros grandes para los pernos 3×M4 de montaje del sensor, agujeros pequeños adicionales para paso de cableado/alineación). Es la versión que corresponde a la interfaz mecánica final una vez que el sensor esté integrado.

**Versión B — imprimible ahora, para pruebas del simulador:**

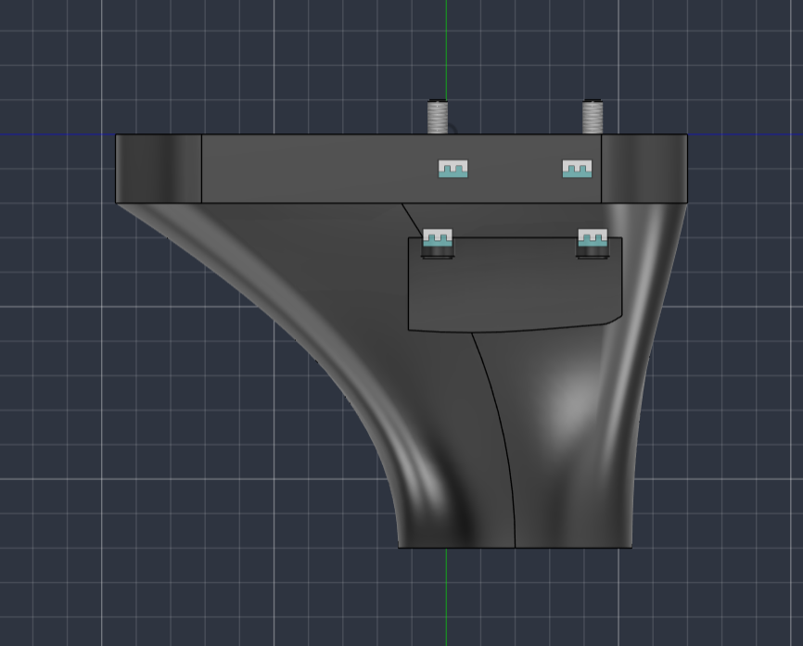
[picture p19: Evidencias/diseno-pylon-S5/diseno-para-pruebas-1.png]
Diseño para pruebas — vista isométrica
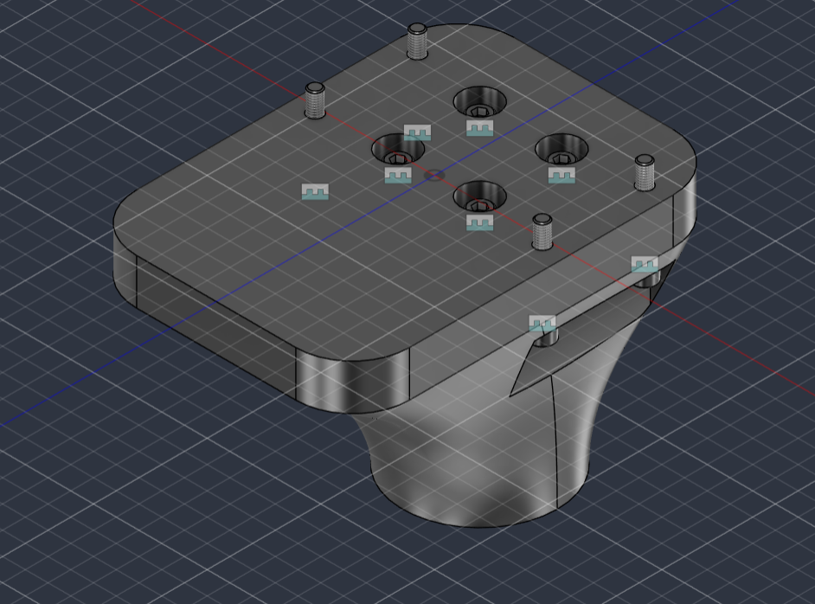
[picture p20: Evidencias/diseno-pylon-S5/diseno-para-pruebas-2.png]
Diseño para pruebas — vista lateral
|  |  |
|---|---|
| Vista superior con los insertos roscados y tornillos visibles | Vista lateral sobre la transición cónica hacia el pylon |

Mismo volumen general que la versión A, pero con insertos roscados (heat-set) y tornillos como referencia mecánica temporal, sin el cuerpo del sensor real. Esta es la pieza que se va a imprimir de inmediato, para poder avanzar con las pruebas de ajuste/ensamblaje en el simulador sin quedar bloqueados esperando la llegada física de la celda de carga comprada.

Esta doble vía (versión final dimensionada al sensor + versión imprimible simplificada) responde directamente a dos pendientes heredados de la S4 en `Diseño mecánico del pylon`: el bracket/adaptador para montar la celda elegida, y el boceto físico de la ubicación real de la celda — ambos seguían "sin avance" hasta esta semana. Quedan todavía sin correr la validación estructural en Fusion 360 (Static Stress Simulation) de esta geometría específica y el caso de carga puntual ~1200 N observado en la S3.

---

## 4. Diseño del adaptador para el sensor de distancia (VL53L1X)

En paralelo al diseño del pylon, se empezó el diseño en Fusion 360 de un adaptador/soporte que sujeta el sensor de distancia VL53L1X (componente enlazado `VL53l1X v1:1`, junto con `ESP32 v1:1`) sobre la plataforma del simulador — archivo de pieza `SENSOR DISTANCIA AGARRI...` dentro del ensamble general `SIMULADOR v3`, con las piezas relacionadas `PLACA BASE v3` y `SOPORTECAJA v1` también en edición esta semana.

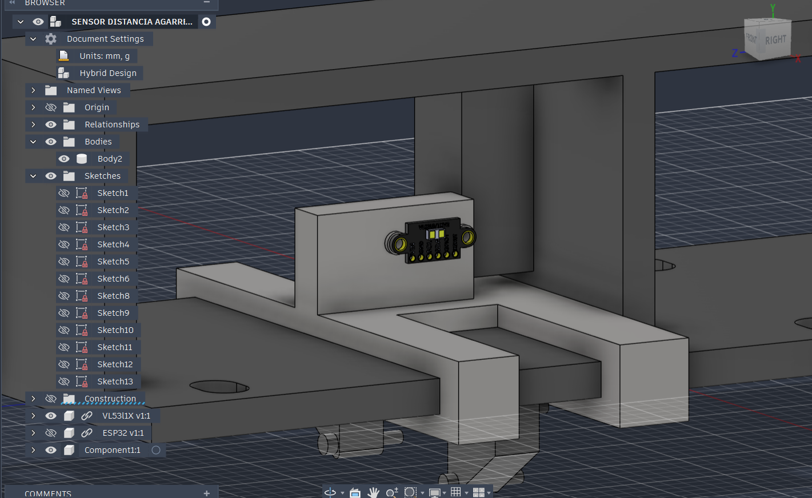
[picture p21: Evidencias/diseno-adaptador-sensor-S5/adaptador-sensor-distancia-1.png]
Adaptador del sensor de distancia — iteración en curso
|  |
|---|
| Vista del adaptador (pieza en L) con el módulo VL53L1X montado, dentro del árbol de bocetos/cuerpos de la pieza en Fusion 360 |

Es una iteración temprana: el diseño ya sostiene el sensor en la posición esperada, pero todavía está en revisión — en el ensamble general (`SIMULADOR v3`) se corrió un chequeo de interferencia (Utilities → Inspect → Interference) entre el soporte en ángulo y la placa base para detectar colisiones antes de imprimir. Queda pendiente resolver esas interferencias (si las hay) y definir la fijación final del adaptador a la plataforma.

---

## Próximos pasos

- Escribir al vendedor (QILICHUANGAN / QL Sensor) para confirmar el tipo de salida real (mV/V crudo vs. amplificado) de la celda comprada, compatibilidad con el ADS1256 ya decidido — señal de alerta pendiente de la propia comparativa ("Push-Pull").
- Guardar las 4 imágenes de las dos versiones del diseño del pylon en `Evidencias/diseno-pylon-S5/` con los nombres usados en la Sección 3, para activar los enlaces del resumen.
- Imprimir la versión B (imprimible, con insertos + tornillos) y correr las pruebas de ajuste/ensamblaje pendientes en el simulador.
- Correr la validación estructural en Fusion 360 (Static Stress Simulation) de la versión A una vez confirmada la capacidad final del sensor, incluyendo el caso de carga puntual ~1200 N heredado de la S3.
- Evaluar el cambio de IMU (MPU6050 → LSM6DSR o ICM-45686) y, en paralelo, diseñar una marca/tope mecánico de referencia para el pivote, antes de repetir la validación cuantitativa del homing que quedó pendiente desde la S4.
- Resolver las interferencias detectadas (si las hay) entre el adaptador del sensor de distancia y la placa base/soporte, y cerrar el diseño de fijación del adaptador a la plataforma.

---

## Fuentes

- `Reportes-Semanales/S5/Comparativa-LoadCells-S5.md` — comparativa y recomendación de celdas de carga y electrónica de lectura (31/08/2026).
- `Estado-del-arte/REFERENCIA DE POSICION ABSOLUTA/Comparativa-IMU-Bajo-Drift.md` — diagnóstico y comparativa de IMU de bajo drift (31/08/2026).
- `Estado-del-arte/SENSORES DE FUERZA/PYLON/Comparativa-Sensores-Fuerza-Axial-Pylon.md` — requisitos P5 y comparativa previa de sensores (19/08/2026).
- `Firmware/homing_absoluto/homing_absoluto.ino` — prototipo de homing donde se observó el problema de repetibilidad que motivó la comparativa de IMU.
- `Reportes-Semanales/S4/Pendientes.md` — pendientes heredados de selección de sensor de fuerza y diseño mecánico del pylon.
- `Evidencias/diseno-adaptador-sensor-S5/adaptador-sensor-distancia-1.png` — captura del adaptador del sensor VL53L1X en Fusion 360 (08/09/2026).

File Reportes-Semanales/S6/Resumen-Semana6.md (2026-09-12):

# Resumen de trabajo — Semana 6

**Período:** 05/09/2026 – 11/09/2026
**Responsable:** Alessandro Jesus Felix Tello

Resumen narrativo de la semana, complementario a `Pendientes.md` (mismo directorio, heredado de la S5) y al resumen de la semana anterior (`S5/Resumen-Semana5.md`).

El foco de la semana estuvo en dejar funcionando la transmisión inalámbrica del BNO055 (DFRobot) por WiFi en modo Access Point propio del ESP32, en encontrar y corregir un bug crítico dentro de la librería `DFRobot_BNO055` que impedía leer el sensor de forma sostenida, y en construir las herramientas de validación y calibración necesarias para que la captura del "0°" de referencia (usada por el homing del pivote) sea confiable: registro a CSV con estadística de ruido, y calibración de acelerómetro de 6 posiciones.

---

## 1. Transmisión WiFi del BNO055 en modo Access Point propio

Se armaron dos sketches (`Firmware/test_wifi_udp_bno055/` y `Firmware/test_wifi_ap_bno055/`) que envían las lecturas del BNO055 por UDP en vez de por cable, usando la librería **DFRobot_BNO055** (no Adafruit_BNO055) por corresponder al módulo Fermion SEN0374 que se está usando. La versión AP hace que el ESP32 cree su propia red WiFi (`LIBRA_ESP32`, IP fija `192.168.4.1`) en vez de unirse a una red existente — evitando el problema de que la red de la universidad usa autenticación WPA2-Enterprise, incompatible con el código simple de conexión WiFi, y evitando también el riesgo de aislamiento cliente/AP típico de redes institucionales.

**Bug crítico encontrado y corregido:** al probar la transmisión, el sensor reportaba `Euler[...]=0.00,0.00,0.00` de forma permanente después de los primeros segundos. La causa, encontrada leyendo el código fuente de la librería, es que la función interna que lee cualquier dato por I2C (`readReg`) llama a `Wire.begin()` en **cada lectura** (decenas de veces por segundo), y reinicializar el bus I2C del ESP32 con esa frecuencia termina rompiendo la comunicación de forma silenciosa — sin ningún mensaje de error. Se corrigió eliminando esa llamada redundante de `DFRobot_BNO055.cpp` (queda comentado en el código el motivo del cambio, para quien revise la librería más adelante).

---

## 2. Validación de ruido del sensor — pruebas "sensor quieto"

Se construyó `log_csv_bno055.py`, que registra a CSV las lecturas del sensor por cable (sirve como respaldo de depuración independiente del WiFi) y calcula automáticamente el promedio y la desviación estándar de heading/roll/pitch y aceleración lineal — la métrica que hacía falta para la validación de ruido pendiente desde la S4/S5 (`Comparativa-IMU-Bajo-Drift.md`).

Antes de corregir el bug de la librería, las dos primeras pruebas (10/09) no fueron utilizables: la primera mostró `calib=0,0,0,0` durante toda la captura (sensor sin calibrar) y un heading con salto 0°/360° que invalida el cálculo lineal de desviación estándar; la segunda salió enteramente en `0.000` — el síntoma que llevó a encontrar el bug de arriba. Ver el diagnóstico completo en `Evidencias/pruebas-imu-S5/Analisis-Prueba-Quieto-S5.md`.

Con la librería ya corregida, cinco repeticiones de 30 s dieron:

| repetición | roll std | pitch std | calib (sys,gyro,acc,mag) |
|---|---|---|---|
| 1 | 0.060° | 0.407° | 0,3,0,0 |
| 2 | 0.474° | 0.505° | 0,3,0,0 |
| 3 | 0.369° | 0.333° | 0,3,0,0 |
| 4 | 0.315° | 0.539° | 0,3,0,0 |
| 5 | 0.495° | 0.291° | 0,3,0,0 |

El giroscopio calibra solo (3/3) pero el acelerómetro y el magnetómetro se quedaron en 0/3 en las cinco pruebas — de ahí que roll/pitch (que dependen del acelerómetro) fueran razonablemente estables pero no tan precisos como deberían, y que heading (que depende casi por completo del magnetómetro) resultara inutilizable (llegó a variar más de 150° en una sola prueba de 30 s estando quieto).

**Filtro de suavizado — EMA, no Kalman ni ML:** se investigó qué tipo de filtro correspondía para las micro-variaciones y se decidió por un promedio móvil exponencial (matemáticamente el mismo filtro que un pasabajos IIR de un polo), en vez de un filtro de Kalman o un modelo de machine learning. Razón: el BNO055 ya hace fusión sensorial interna equivalente a un Kalman/complementario (modo NDOF); filtrar de nuevo con Kalman la salida ya fusionada sería redundante. Con los datos de la primera prueba, un EMA con alpha=0.05 bajó la desviación estándar de pitch de 1.84° a 1.16°:

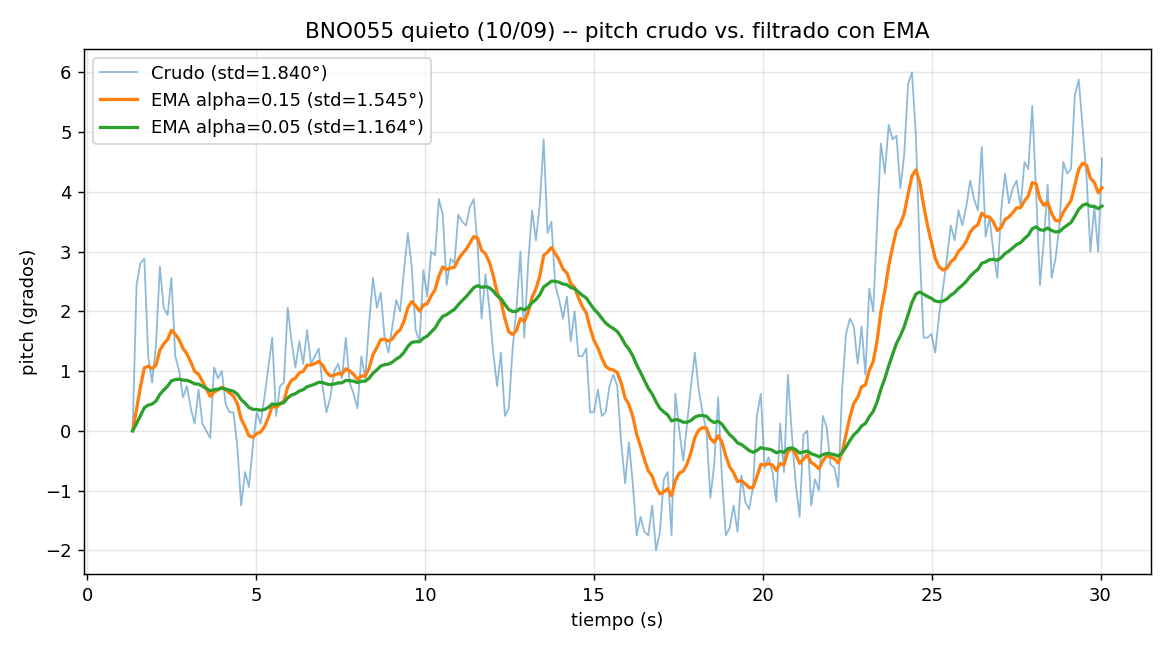
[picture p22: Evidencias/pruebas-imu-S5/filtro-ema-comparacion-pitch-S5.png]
Comparación crudo vs. EMA — pitch
|  |
|---|
| Pitch crudo vs. filtrado con EMA (alpha=0.15 y alpha=0.05), datos de la prueba "sensor quieto" del 10/09 |

---

## 3. Precisión del "cero absoluto": captura mejorada + calibración de acelerómetro de 6 posiciones

Dado que el objetivo final es que el sistema pueda fijar el 0° de referencia del pivote con confianza (mismo problema de fondo que motivó `homing_absoluto.ino` en la S4), se hicieron dos mejoras concretas sobre los sketches de BNO055:

- **Captura de cero más robusta:** la función que fija el cero absoluto (comando `'z'`) ahora promedia el doble de muestras (200 en vez de 100), reporta la desviación estándar lograda en esa captura específica, y **rechaza** guardar el cero si el sensor se movió más de 0.5° durante la toma — antes se guardaba sin avisar aunque la captura fuera mala.
- **Calibración de acelerómetro de 6 posiciones (`calibrar_acelerometro.py`):** dado que el acelerómetro se quedaba sin calibrar (0/3) en todas las pruebas, se construyó una calibración alternativa a la auto-calibración por movimiento continuo del propio chip (poco práctica): el script guía por 6 posturas estáticas (una por cada cara de un cubo imaginario), detecta solo qué eje quedó apuntando a la gravedad en cada una, calcula el sesgo (offset) de cada eje, y lo escribe directo en los registros internos del BNO055 (`setAxisOffset`, requiere modo CONFIG) — la única forma de que la mejora impacte realmente los ángulos Euler, ya que esos los calcula el propio chip con su acelerómetro interno. La calibración queda guardada en la flash del ESP32 y se reaplica sola en cada arranque, así que no hace falta repetirla en cada sesión de prueba.

Nota importante confirmada durante esta investigación: no existe ningún atajo de software/IA para saltarse la calibración física del acelerómetro — separar el sesgo del sensor de la dirección de la gravedad requiere, matemáticamente, verlo quieto en más de una orientación; con el sensor en una sola posición esa información no está en los datos. Lo que sí se logró fue reemplazar la calibración "en movimiento" (poco controlable) por una calibración de posturas estáticas, más fácil de ejecutar de forma repetible.

---

## 4. Avance en el diseño mecánico del pylon y montaje de electrónica

En paralelo al trabajo de firmware, se actualizó el diseño en Fusion 360 del bloque superior del pylon (el mismo de la Sección 3 de `S5/Resumen-Semana5.md`), y se registró una vista del montaje de la electrónica (ESP32 y un módulo adicional) en la parte inferior de la plataforma, junto al bloque del pylon:

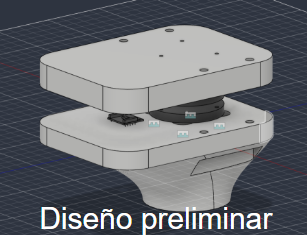
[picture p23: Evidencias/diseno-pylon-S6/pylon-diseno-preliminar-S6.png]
Diseño preliminar del bloque del pylon
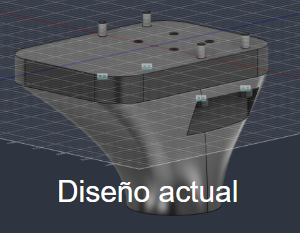
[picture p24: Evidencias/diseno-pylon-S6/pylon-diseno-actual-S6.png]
Diseño actual del bloque del pylon
|  |  |
|---|---|
| Diseño preliminar — placas superior e inferior con el sensor visible entre ambas | Diseño actual — bloque más integrado con la transición cónica hacia el pylon |

| ESP32 y electrónica bajo la plataforma, junto al bloque del pylon |
|---|
| Vista de la parte inferior de la plataforma: ESP32 y un módulo adicional montados junto al bloque del pylon |

Quedan pendientes de precisar en el próximo reporte: qué cambió específicamente entre el diseño preliminar y el actual (dimensiones, forma de la transición cónica, fijación), y qué módulo es el que aparece junto al ESP32 en la vista de montaje — se documentan aquí las tres imágenes para no perder el avance visual mientras se completa esa descripción.

---

## Próximos pasos

- Correr `calibrar_acelerometro.py` y repetir las pruebas de `log_csv_bno055.py` para confirmar que la calibración de acelerómetro efectivamente baja la desviación estándar de roll/pitch por debajo de los valores de esta semana.
- Repetir la prueba "sensor quieto" con el magnetómetro también calibrado (o evaluar si heading realmente hace falta para el caso de uso del pivote, que es principalmente roll/pitch por gravedad).
- Retomar la decisión pendiente de la S5 sobre el reemplazo de IMU (LSM6DSR/ICM-45686) — ahora con el BNO055 funcionando de forma confiable por WiFi, evaluar si sigue conviniendo migrar o si el BNO055 calibrado ya cubre el caso de uso.
- Aplicar el mismo criterio de "referencia física fija" (Hall + imán en el punto de 0°) evaluado para el pivote en `Pendientes.md`, una vez que la precisión del cero por IMU esté confirmada con el acelerómetro ya calibrado.

---

## Fuentes

- `Evidencias/pruebas-imu-S5/Analisis-Prueba-Quieto-S5.md` — análisis detallado de las pruebas "sensor quieto" (10/09/2026), incluyendo los dos archivos CSV crudos y el hallazgo del bug de la librería.
- `Firmware/test_wifi_ap_bno055/test_wifi_ap_bno055.ino` y `Firmware/test_wifi_udp_bno055/test_wifi_udp_bno055.ino` — sketches con la corrección de la librería, la captura de cero mejorada, y la calibración de acelerómetro.
- `Firmware/test_wifi_ap_bno055/visor_python/log_csv_bno055.py` y `calibrar_acelerometro.py` — herramientas de registro y calibración construidas esta semana.
- [Filter-IMU (comparación moving average / low-pass / Kalman en datos reales de IMU)](https://github.com/keatinl1/Filter-IMU/blob/main/README.md)
- [Noise Removal in The IMU Sensor Using Exponential Moving Average with Parameter Selection (ROV)](https://www.researchgate.net/publication/362050644_Noise_Removal_in_The_IMU_Sensor_Using_Exponential_Moving_Average_with_Parameter_Selection_in_Remotely_Operated_Veh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)
- [Kalman filter vs Complementary filter](https://robottini.altervista.org/kalman-filter-vs-complementary-filter)
- `Reportes-Semanales/S5/Pendientes.md` — pendientes heredados donde se registraron los hallazgos del 10/09 en detalle.
- `Evidencias/diseno-pylon-S6/` — imágenes del diseño preliminar/actual del bloque del pylon y del montaje de electrónica bajo la plataforma (12/09/2026).

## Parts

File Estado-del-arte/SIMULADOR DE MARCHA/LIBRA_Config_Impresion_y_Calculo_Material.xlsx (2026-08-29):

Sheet: Config Impresion
LIBRA — Configuración de impresión recomendada (bracket pylon)
Material base: PETG (mejor balance accesible resistencia / imprimibilidad para carga cíclica)
Parámetro | Valor recomendado | Motivo
Material | PETG | Mejor adherencia entre capas que ABS/PLA; accesible en impresoras de escritorio
Temp. nozzle | 235–245 °C | Rango típico PETG; hacia el extremo alto mejora fusión entre capas
Temp. cama | 80–85 °C | Evita warping y mejora adhesión a la base
Altura de capa | 0.16 mm | Capas finas → mejor fusión interlayer → menor penalización en Z
Ancho de línea | 0.42 mm (105% de boquilla 0.4 mm) | Mejora compactación de cada cordón
N° de paredes (perímetros) | 4 | En piezas chicas, las paredes cargan la mayor parte del esfuerzo — priorizar sobre infill
Capas sólidas superior/inferior | 6 | Rigidiza la superficie y evita ver el patrón de infill
Patrón de infill | Gyroid | Comportamiento más isotrópico y eficiente (exponente n,m más bajo) que grid/rectilinear
% de infill | 60% | Balance entre resistencia y peso/tiempo; ver hoja Calculadora para otros valores
Velocidad de impresión | 40–50 mm/s | Velocidad moderada mejora fusión entre capas, reduce stringing
Ventilación (fan) | 30–50% | PETG no tolera enfriamiento agresivo; fan alto fragiliza la unión entre capas
Orientación de impresión | Eje de carga axial del pylon alineado con el plano XY (capas) | Evita que la carga principal trabaje perpendicular a las capas (dirección Z, la más débil)
Flujo de trabajo
1) Imprime con esta configuración (o la variante de infill que estés probando). 2) Anota en la hoja 'Calculadora Iteraciones' el peso estimado que da tu slicer para esa combinación exacta de paredes/infill/patrón, junto con el volumen del CAD. 3) La hoja calcula la densidad efectiva real y escala rigidez/resistencia con el modelo de sólidos celulares (Gibson-Ashby). 4) Copia los 5 valores de las columnas 'Para Ansys' directo a Engineering Data (Density, Young's Modulus, Poisson's Ratio, Yield Strength, Ultimate Strength).

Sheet: Propiedades Base
Propiedades base al 100% sólido (valores conservadores, dirección Z / interlayer)
Editables en amarillo. Fuente: estimaciones conservadoras de literatura FDM, no datasheet certificado — para screening/comparación, no para reporte final.
Material | Densidad rho (g/cm3) | E (GPa) | Poisson | Yield (MPa) | Ultimate (MPa)
PLA | 1.24 | 2.30 | 0.36 | 20.00 | 28.00
PETG | 1.27 | 1.80 | 0.38 | 22.00 | 30.00
ABS | 1.04 | 2.00 | 0.35 | 16.00 | 20.00
Nylon PA12 | 1.02 | 1.50 | 0.39 | 30.00 | 40.00
Nylon-CF (tipo Onyx) | 1.20 | 3.00 | 0.35 | 28.00 | 38.00
Nota: | Estos valores representan el extremo débil (interlayer/Z) reportado en estudios de caracterización de FDM, usados a propósito para no sobreestimar resistencia. Reemplázalos por datos de datasheet o ensayo propio si el material final ya está definido.

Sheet: Patrones Infill
Exponentes de escalado por patrón de infill (modelo de sólidos celulares)
E_efectiva = E_sólido x (rho_efectiva/rho_sólido)^n | Resistencia_efectiva = Resistencia_sólido x (rho_efectiva/rho_sólido)^m
Patrón de infill | n (rigidez) | m (resistencia) | Comentario
Grid / Rectilinear | 2.00 | 1.50 | Estructura tipo flexión — cae más rápido con la densidad
Cubic | 1.80 | 1.40 | Intermedio
Triangular | 1.60 | 1.30 | Más eficiente que grid, carga por tracción en las diagonales
Gyroid | 1.50 | 1.30 | El más isotrópico y eficiente de los comunes en slicers

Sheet: Calculadora Iteraciones
Calculadora por iteración — de config. de impresión a valores para Ansys
Llena solo las columnas en amarillo. El resto se calcula solo. Una fila = una iteración de impresión.
ENTRADAS (llenar) |  |  |  |  |  | DENSIDAD EFECTIVA |  |  | PROPIEDADES ESCALADAS |  |  |  |  |  | VALORES PARA ANSYS (Engineering Data)
Iteración | Material base | Patrón infill | Infill (%) | Peso estimado slicer (g) | Volumen CAD (cm3) | rho_solido (g/cm3) | rho_efectiva (g/cm3) | rho_efectiva / rho_solido | n | m | Poisson | E_efectiva (GPa) | Yield_efectiva (MPa) | Ultimate_efectiva (MPa) | Densidad (kg/m3) | Young's Modulus (Pa) | Poisson's Ratio | Yield Strength (Pa) | Ultimate Strength (Pa)
Iter 1 | PETG | Grid / Rectilinear | 60 | 179.91 | 223.8 | 1.27 | 0.80 | 0.63 | 2.00 | 1.50 | 0.38 | 0.72 | 11.1 | 15.1 | 803.8873995 | 721199647.7 | 0.38 | 11079239.01 | 15108053.2
Iter 2 | Nylon-CF (tipo Onyx) | Grid / Rectilinear | 60 | 164.88 | 223.8 | 1.20 | 0.74 | 0.61 | 2.00 | 1.50 | 0.35 | 1.13 | 13.5 | 18.3 | 736.7292225 | 1130770724 | 0.35 | 13469392.46 | 18279889.76
Iter 3
Iter 4
Iter 5
Iter 6
Iter 7
Iter 8
Iter 9
Iter 10
Iter 11
Iter 12
Cómo pasar a Ansys:
En Engineering Data -> nuevo material -> Properties: agrega 'Density' (columna Q, kg/m3), 'Isotropic Elasticity' con Young's Modulus (columna R, Pa) y Poisson's Ratio (columna S), y 'Tensile Yield Strength' / 'Tensile Ultimate Strength' (columnas T y U, en Pa). Crea un material nuevo por fila/iteración para comparar el Safety Factor entre configuraciones de impresión.

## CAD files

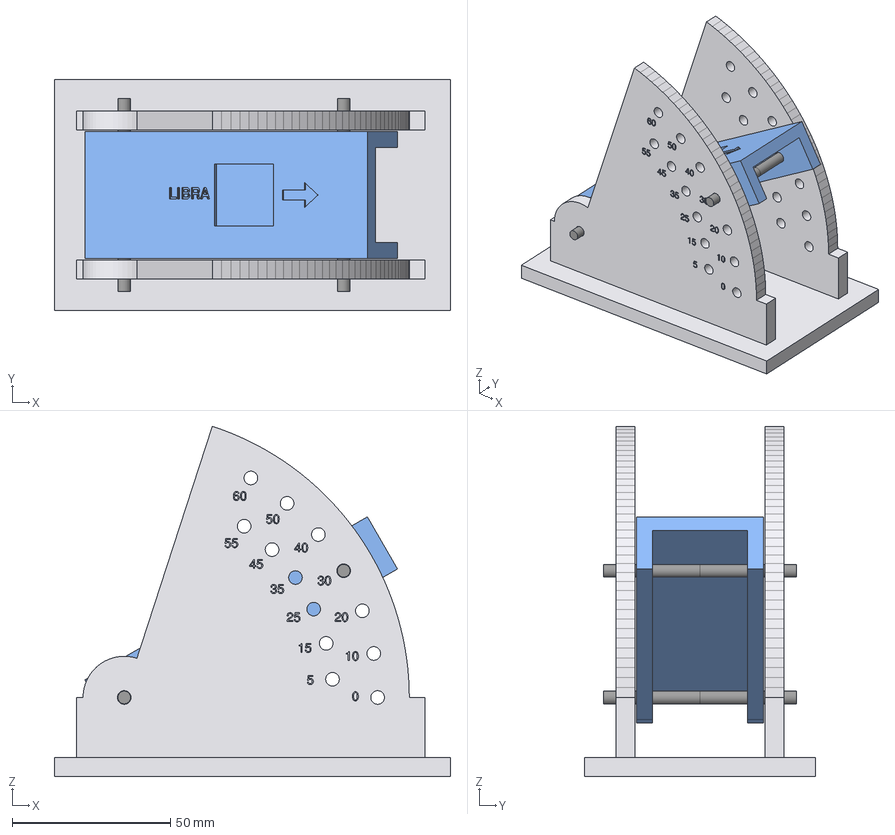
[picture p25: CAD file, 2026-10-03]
Firmware/test_wifi_ap_bno055/soporte_angulos_imu/ensamble_soporte_30grados.step
125.0 x 73.0 x 110.6 mm
base_arco_indexado
plataforma_imu
perno_pivote_M4
perno_indexado_M4

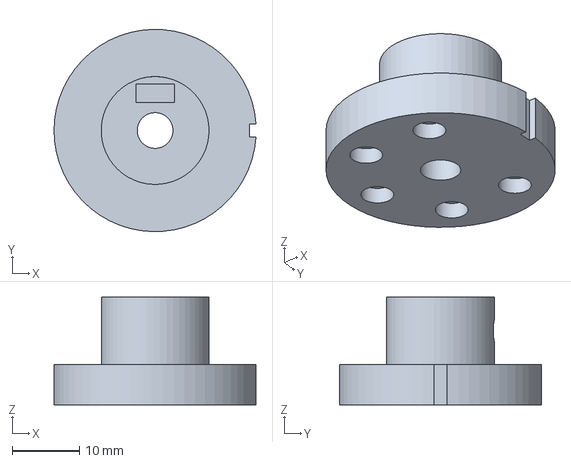
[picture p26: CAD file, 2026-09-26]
Claude outputs/collarin_imanes.step
30.0 x 30.0 x 16.0 mm

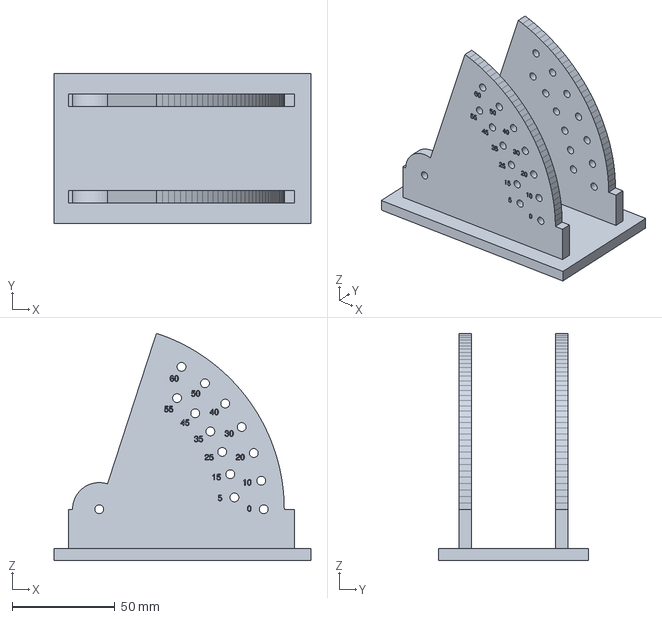
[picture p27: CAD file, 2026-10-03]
Firmware/test_wifi_ap_bno055/soporte_angulos_imu/base_arco_indexado.step
125.0 x 73.0 x 110.6 mm

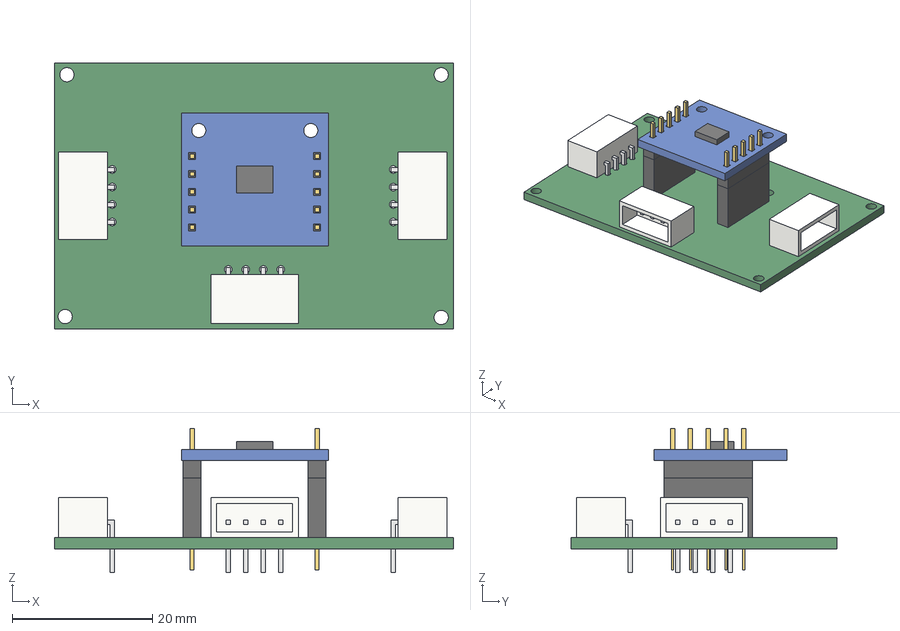
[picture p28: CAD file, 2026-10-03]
PCB_LIBRA_IMU.step
57.0 x 38.0 x 20.6 mm
PCB
CN2_body
CN2_pins
CN3_body
CN3_pins
CN4_body
CN4_pins
J1_female_header_1x5
J1_female_pins
U1_male_header_1
U1_male_pins_1
J2_female_header_1x5
J2_female_pins
U1_male_header_2
U1_male_pins_2
U1_BNO055_module_PCB
U1_BNO055_chip

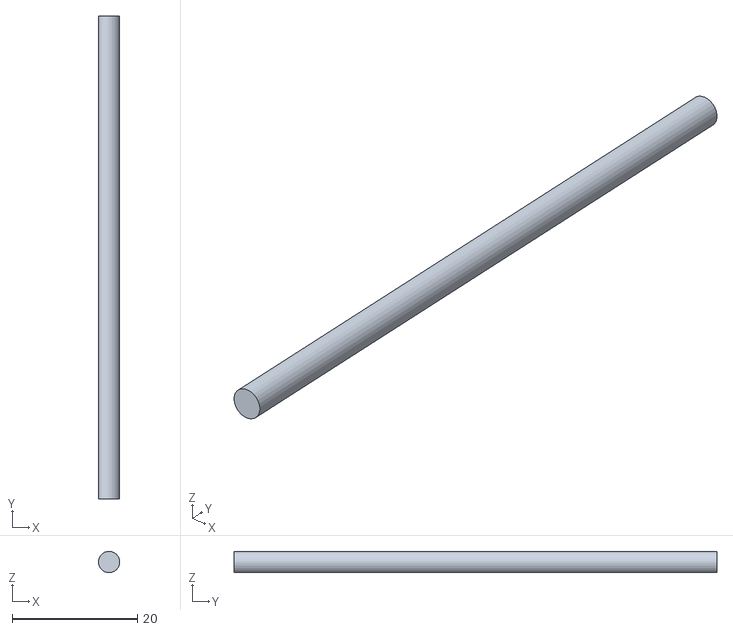
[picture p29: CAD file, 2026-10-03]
Firmware/test_wifi_ap_bno055/soporte_angulos_imu/pasante_imu.stl
3.39 x 77.0 x 3.39

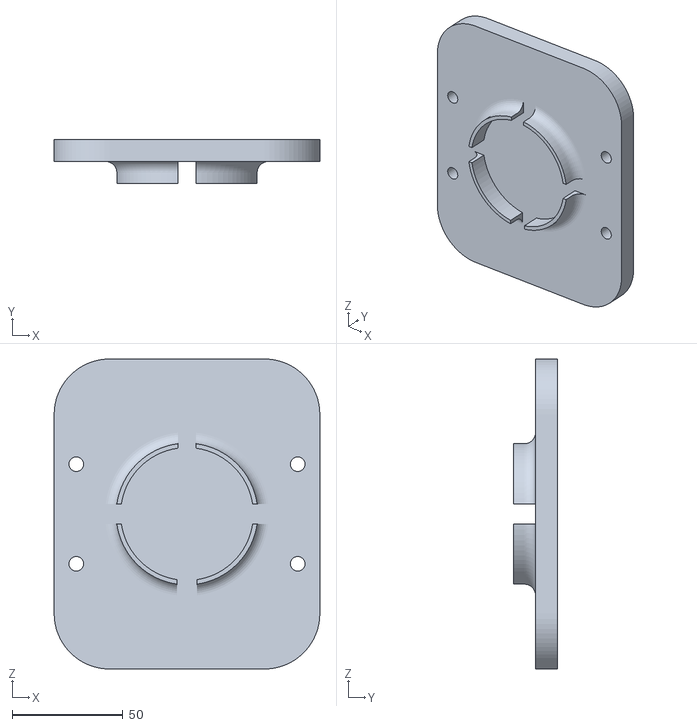
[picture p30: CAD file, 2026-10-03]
Firmware/test_wifi_ap_bno055/soporte_angulos_imu/parte de abajo.stl
120.0 x 20.0 x 140.0

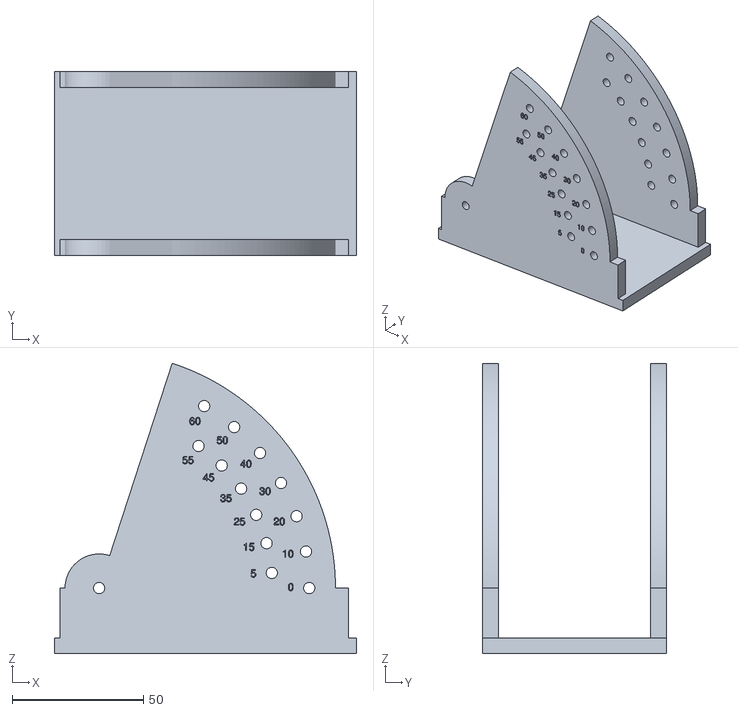
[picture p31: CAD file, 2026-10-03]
Firmware/test_wifi_ap_bno055/soporte_angulos_imu/base_imu.stl
115.0 x 70.0 x 110.6

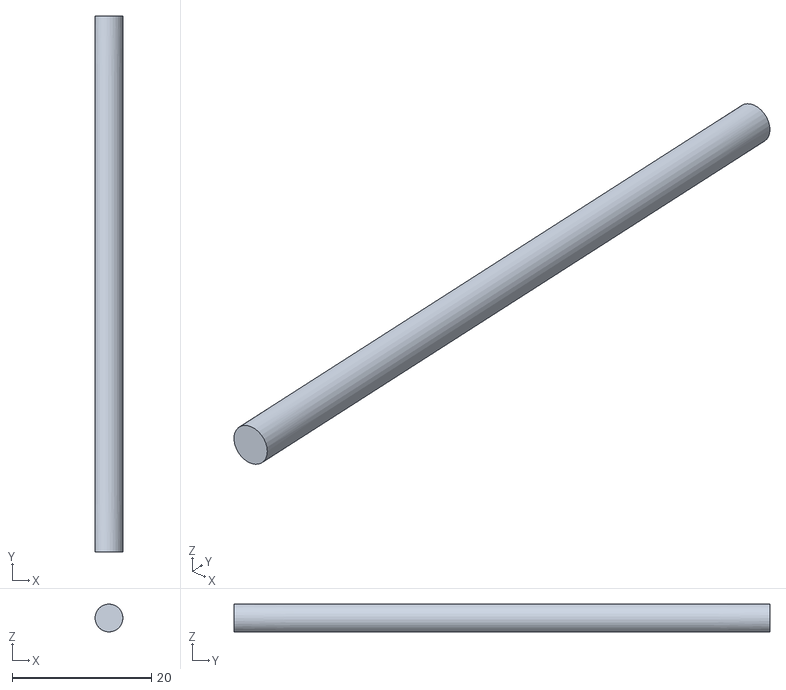
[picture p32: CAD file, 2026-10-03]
Firmware/test_wifi_ap_bno055/soporte_angulos_imu/baritas_angulos.stl
4.00 x 77.0 x 3.99

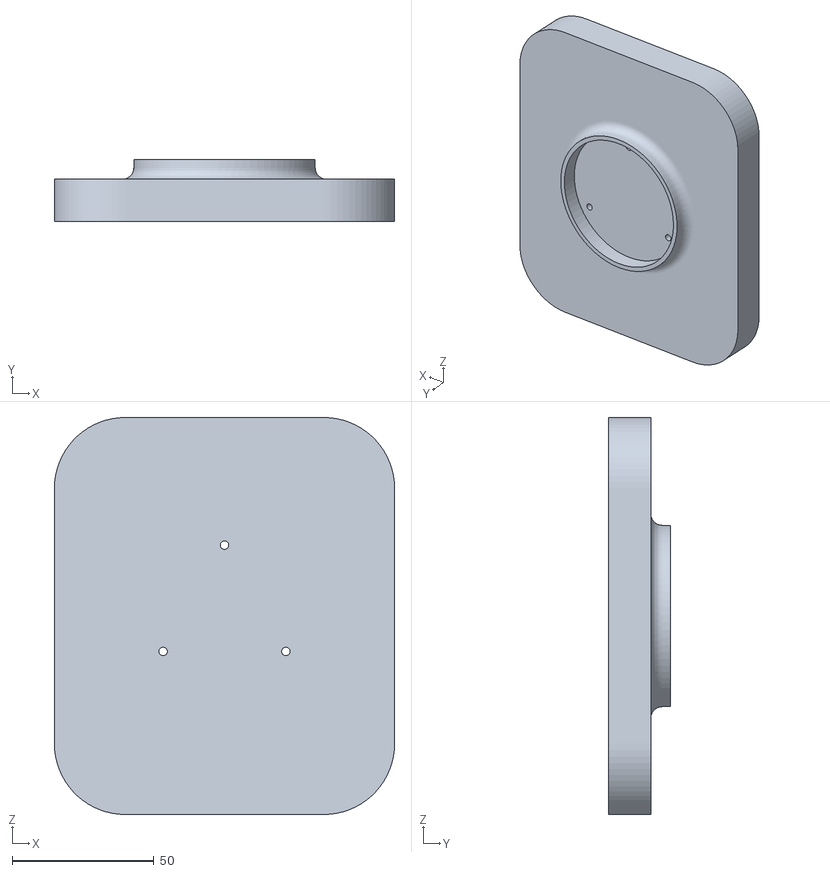
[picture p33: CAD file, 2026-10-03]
Firmware/test_wifi_ap_bno055/soporte_angulos_imu/partedearroba.stl
120.0 x 22.0 x 140.0

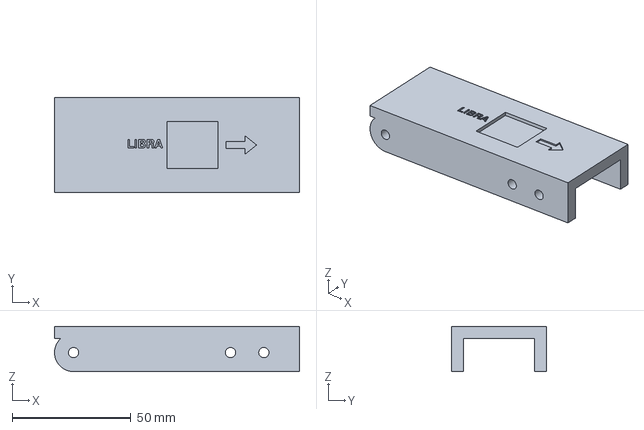
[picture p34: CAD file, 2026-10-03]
Firmware/test_wifi_ap_bno055/soporte_angulos_imu/plataforma_imu.step
103.0 x 40.0 x 19.0 mm

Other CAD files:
Firmware/homing_husillo_hall/collarin_imanes/collarin_imanes.stl
Firmware/test_wifi_ap_bno055/soporte_angulos_imu/plataforma_imu.stl

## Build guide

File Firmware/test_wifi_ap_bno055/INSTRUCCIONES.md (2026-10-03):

# Test WiFi con red propia del ESP32 (modo Access Point) — BNO055 DFRobot

Versión de `test_wifi_udp_bno055.ino` que **no depende de ninguna red WiFi existente**. En vez de que el ESP32 se una a tu WiFi de casa o de la universidad, aquí el ESP32 crea su propia red (modo Access Point / AP) y tu laptop se conecta directo a esa red — sin router de por medio, sin login enterprise de la universidad, sin depender de que haya WiFi disponible donde estés probando el simulador.

Útil especialmente porque el WiFi de la universidad (PUCP-Alumnos, eduroam) normalmente pide usuario + contraseña (WPA2-Enterprise) y **no** funciona con el código simple de `WiFi.begin(ssid, password)` que usan las otras dos carpetas de WiFi — esta variante evita el problema por completo.

## 1. Conexionado

Igual que siempre: BNO055 → ESP32, VCC-3V3, GND-GND, SDA-**GPIO17**, SCL-**GPIO16** (bus `Wire1`, pinout final de la PCB; hasta la S8 era SDA-GPIO21, SCL-GPIO22).

## 2. Configurar el sketch (opcional)

Por defecto ya funciona sin tocar nada:

```cpp
const char* AP_SSID     = "LIBRA_ESP32";
const char* AP_PASSWORD = "libra2026";
```

Puedes cambiar el nombre/contraseña de la red si quieres — el password debe tener **mínimo 8 caracteres**, si no el ESP32 crea la red sin contraseña (abierta). A diferencia de las otras dos carpetas de WiFi, **aquí no hay ninguna IP que configurar a mano** — todo es automático (ver la sección "Cómo funciona" abajo si quieres entender por qué).

## 3. Software (Arduino IDE)

Misma librería que `test_wifi_udp_bno055.ino`: **DFRobot_BNO055**. Carga el sketch y abre el Monitor Serie a 115200 — debería mostrar algo como:

```
Red WiFi propia creada: "LIBRA_ESP32"
IP del ESP32 (siempre es esta en modo AP): 192.168.4.1
BNO055 detectado correctamente.
```

## 4. Conectar tu laptop a la red del ESP32

En el panel de WiFi de Windows, busca y conéctate a **"LIBRA_ESP32"** (o el nombre que hayas puesto) con la contraseña configurada — exactamente como te conectas a cualquier otra red.

**Mientras estés conectado a esta red, tu laptop probablemente pierda acceso a internet** — es normal, el ESP32 no reenvía tráfico a internet, solo sirve como canal directo entre él y tu laptop. Si necesitas internet a la vez (para buscar algo, etc.), tendrás que desconectarte de esta red momentáneamente o usar otro dispositivo.

## 5. Visor en tiempo real (Python)

```
cd visor_python
pip install -r requirements.txt
python visor_wifi_ap_bno055.py
```

A diferencia de `visor_wifi_bno055.py`, este **no imprime ninguna IP para copiar a ningún lado** — el ESP32 siempre es `192.168.4.1` en este modo, así que ya viene fijo en el script. En cuanto tu laptop esté conectada a la red del ESP32 (paso 4), el gráfico debería empezar a moverse solo.

Los botones son los mismos de siempre ("Zero grafico local", "Cero absoluto (flash)", "Borrar cero (flash)") — la diferencia es que aquí ya saben de entrada a qué IP mandar los comandos, no necesitan aprenderla de un primer paquete.

## 6. Cómo funciona la direcciones IP en este modo (por si te preguntas por qué no hay que configurar nada)

- El ESP32 en modo Access Point **siempre** es `192.168.4.1` — es el valor por defecto de la librería WiFi de Espressif, no depende de tu red.
- Tu laptop, al conectarse, recibe automáticamente una IP en el mismo rango (típicamente `192.168.4.2`) que el propio ESP32 le asigna — no necesitas verla ni escribirla en ningún lado.
- El ESP32 manda los datos por **broadcast** a `192.168.4.255` en vez de a una IP fija de PC — le llega a cualquier laptop conectada a su red, así que no hace falta el paso de "averigua tu IP y cópiala en el sketch" que sí tenían las otras dos versiones.

## 7. Cuándo conviene esta versión vs. las otras dos

- **Esta (AP propio):** ideal para pruebas de banco/laboratorio sin depender de infraestructura de red, o cuando la única red disponible es la de la universidad (enterprise). Límite: el alcance es el del propio WiFi del ESP32 (más corto que un router de verdad), y solo funciona mientras tu laptop esté conectada a ESA red (no a la de siempre).
- **`test_wifi_udp_bno055` (se une a una red existente):** mejor si ya tienes un WiFi doméstico o un hotspot de celular confiable en el lugar de la prueba, y quieres que tu laptop mantenga acceso a internet a la vez.

Las dos comparten la misma limitación de fondo: UDP sin confirmación de entrega — ver la sección correspondiente en `test_wifi_udp_bno055/INSTRUCCIONES.md` si no la has leído.

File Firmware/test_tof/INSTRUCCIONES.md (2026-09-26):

# Driver de prueba 2x VL53L1X — sensores de distancia ToF (ESP32)

Sketch de prueba para los dos sensores de distancia ToF VL53L1X de la placa
superior. Verifica el cableado I2C, la secuencia de reasignación de
dirección (necesaria porque los dos sensores comparten el mismo bus y la
misma dirección de fábrica) y la lectura básica de distancia — ver el
pinout completo y su justificación en
[`../PCB_placa_superior_PINOUT.md`](../PCB_placa_superior_PINOUT.md) (Secc. 2-4).

## 1. Conexionado

| Señal | ESP32 | Notas |
|---|---|---|
| I2C SDA (compartido, ambos sensores) | GPIO21 | pin I2C por defecto del ESP32 |
| I2C SCL (compartido, ambos sensores) | GPIO22 | pin I2C por defecto del ESP32 |
| SHUT / XSHUT ToF1 (U3) | GPIO25 | activo en bajo, imprescindible un GPIO independiente por sensor |
| SHUT / XSHUT ToF2 (U2) | GPIO26 | ídem |
| INT (ambos) | sin conectar (NC) | este sketch lee por *polling*, no usa interrupciones |
| VCC / GND (ambos) | 3.3V / GND | común con el resto del circuito |

## 2. Por qué hace falta reasignar dirección I2C

Los dos VL53L1X vienen de fábrica con la **misma dirección fija (0x29)**, así
que no se pueden diferenciar en el mismo bus solo por dirección. El sketch
resuelve esto con el pin **SHUT** de cada uno:

1. Mantiene a **ambos** en reset (SHUT en bajo).
2. Saca a **ToF1** del reset (queda en 0x29, el otro sigue apagado) y le
   asigna la dirección **0x30** con `setAddress()`.
3. Recién ahí saca a **ToF2** del reset — como ToF1 ya se movió a 0x30, ToF2
   puede arrancar en su dirección de fábrica (0x29) sin chocar.

Por eso el orden importa: si se sacara a los dos del reset al mismo tiempo,
ambos responderían en 0x29 y el bus quedaría en conflicto.

## 3. Software (Arduino IDE)

1. Instalar la librería **"VL53L1X" de Pololu**
   ([github.com/pololu/vl53l1x-arduino](https://github.com/pololu/vl53l1x-arduino))
   desde el Library Manager: Herramientas > Administrar Bibliotecas > buscar
   `VL53L1X` > instalar la de Pololu.
2. Abrir `test_tof.ino` como sketch independiente (misma estructura que los
   demás sketches de `Firmware/`).
3. Revisar los pines (`PIN_I2C_SDA`, `PIN_I2C_SCL`, `PIN_SHUT_TOF1`,
   `PIN_SHUT_TOF2`) contra tu cableado real antes de cargar.
4. Cargar y abrir el Monitor Serie a **115200 baudios**.

## 4. Calibración

**Este sketch no tiene comandos de calibración por Serial ni persiste nada
en flash.** A diferencia del HX711 (celda de carga, necesita tara + factor
de escala definidos por el usuario — ver
[`../test_hx711/INSTRUCCIONES.md`](../test_hx711/INSTRUCCIONES.md)) o del
BNO055 (cero absoluto de orientación), el VL53L1X ya viene calibrado de
fábrica: el chip ST hace su propia compensación interna de offset/crosstalk
y entrega la distancia en mm directamente. No hay ningún dato de
calibración de este sketch que se pueda perder — es independiente y no
toca la calibración guardada del HX711 en `test_hx711.ino` (namespaces NVS
distintos, y este sketch ni siquiera usa `Preferences`).

## 5. Qué esperar

Al arrancar, el sketch imprime la secuencia de inicialización y un escaneo
del bus I2C — deberías ver dos dispositivos: **0x29** (ToF2) y **0x30**
(ToF1, reasignado). Si solo aparece uno o ninguno, revisar alimentación y
cableado SHUT/SDA/SCL antes de seguir.

Luego, salida CSV continua: `dist1_mm,status1,dist2_mm,status2`

- `dist1_mm` / `dist2_mm`: distancia medida en milímetros por ToF1 y ToF2.
- `status1` / `status2`: código de estado de la librería Pololu — **0 =
  lectura válida** (`RangeValid`); cualquier otro valor indica una lectura
  no confiable (objeto fuera de rango, señal muy débil, etc.) y no debe
  tomarse como distancia real.

Si ves `ERROR: timeout esperando datos de ToF1/ToF2`, el sketch no está
recibiendo respuesta de ese sensor — lo más común es un problema de
alimentación, cableado SDA/SCL, o que el SHUT correspondiente no llegó a
sacarlo del reset.

## 6. Visor en tiempo real (Python)

Igual que con el HX711, hay un visor gráfico en `visor_python/visor_tof.py`
que lee el puerto serial y grafica la distancia de ambos sensores en vivo.

```
cd visor_python
pip install -r requirements.txt
python visor_tof.py --port COM5
```

## 7. Siguiente paso

- Con ambos sensores respondiendo y dando distancias razonables, definir el
  soporte/orientación mecánica final de cada ToF en la plataforma y, si
  hace falta, migrar la lectura de *polling* a interrupción (usar el pin
  INT de cada sensor) una vez integrado al firmware principal.

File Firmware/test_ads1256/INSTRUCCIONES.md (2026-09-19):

# Driver de prueba ADS1256 — celda de carga (ESP32)

Sketch de prueba para el ADC ADS1256 (24 bits, 8 canales, SPI), elegido en la
[comparativa de sensores de fuerza](../../Estado-del-arte/SENSORES%20DE%20FUERZA/PYLON/Comparativa-Sensores-Fuerza-Axial-Pylon.md)
para leer la celda de carga del pylon. A diferencia de los sketches de IMU
(BNO055/MPU6050, I2C con librerías Adafruit ya hechas), acá no hay librería
de Arduino Library Manager para el ADS1256, así que el protocolo (SPI +
registros) está implementado directo en `test_ads1256.ino`.

**Por qué ADS1256 y no HX711:** el HX711 trae amplificador + ADC integrados
y es más simple de usar, pero es un ADC dedicado (1-2 canales). El ADS1256
tiene 8 canales y la idea es **compartirlo** con los 6 canales analógicos de
la plataforma AMTI (Fx,Fy,Fz,Mx,My,Mz) más adelante — ver
`Reportes-Semanales/S4/Pendientes.md`, sección de la AMTI. Ese trabajo de
multiplexar los 6 canales de la AMTI **sigue pendiente**; este sketch solo
deja listo el canal de la celda de carga (AIN0) y el MUX preparado para
extenderse.

**Estado de la celda de carga:** todavía no hay celda final elegida (ver
Pendientes S4). Por eso este sketch no trae un factor de escala de fábrica:
implementa tara + calibración con una masa patrón conocida, igual que se
haría con cualquier celda. Cuando se elija la celda definitiva, esta misma
rutina de calibración sirve sin cambios.

## 1. Conexionado

**Si tu módulo es el genérico de placa roja que se vende como "Teyleten
Robot ADS1256 24-bit 8-Channel"** (mismo diseño vendido también como
HiLetgo/JESSINIE/otros — ver Secc. 7.1), el header ya viene simplificado a
estos pines (no expone AVDD/DVDD/AGND/DGND/VREFP/VREFN/CLKIN por separado,
ni un pin RESET):

| Módulo (silkscreen) | ESP32 | Notas |
|---|---|---|
| DIN | GPIO23 | MOSI |
| DOUT | GPIO19 | MISO — **ver aviso de niveles lógicos abajo** |
| SCLK | GPIO18 | |
| CS | GPIO5 | |
| DRDY | GPIO4 | entrada; el ADS1256 la pone en LOW cuando hay un dato nuevo listo — **ver aviso de niveles lógicos abajo** |
| PDWN | 5V del módulo | siempre encendido, no se controla por software acá |
| 5V | fuente 5V (no el 3.3V del ESP32) | el módulo es de 5V fijo |
| GND | GND del ESP32 (común) | |
| AIN0...AIN7 | — | canales analógicos; este sketch usa AIN0 (señal) + AINCOM (común, ya interna del módulo) |

No hay pin RESET expuesto en este módulo — por eso el sketch trae
`ADS1256_USE_RESET_PIN` en `0` por defecto (usa solo el comando de software
RESET/init, no un pin físico).

**⚠️ Aviso de niveles lógicos:** este módulo se alimenta a 5V fijos (no se
encontró versión con jumper a 3.3V). Sus salidas hacia el ESP32 (**DOUT** y
**DRDY**) quedan entonces en lógica de 5V, y los pines del ESP32 **no son
tolerantes a 5V** (máximo absoluto ~3.6V) — conectarlos directo puede dañar
el ESP32. Hace falta un **conversor de nivel lógico** (level shifter
bidireccional barato, ej. módulo con TXS0108E o BSS138) entre el módulo y
el ESP32 antes de alimentar todo por primera vez. Para DIN/SCLK/CS/PDWN
(sentido ESP32 → módulo) un 3.3V suele registrar como HIGH igual, pero no
está garantizado por el fabricante — si van a armar el level shifter de
todas formas, pasen esas 4 líneas también.

Si en cambio tenés el módulo con el chip "pelado" (SSOP-28, para diseño de
placa propia) o un breakout distinto que sí expone AVDD/DVDD/AGND/DGND/
VREFP/VREFN/CLKIN por separado, esos pines no son intercambiables con la
tabla de arriba — revisar el datasheet/silkscreen de ese módulo específico
(pinout completo del chip en la Secc. 7.1).

Se usaron los pines VSPI por defecto del ESP32 (18/19/23 + CS en GPIO5) a
propósito, para dejar libres GPIO21/22 (I2C) que ya usan los sketches de IMU
— así se puede tener el ADS1256 (SPI) y un IMU (I2C) conectados al mismo
ESP32 al mismo tiempo sin conflicto de pines, que es justo la arquitectura
multi-sensor que pide el proyecto.

**Señal de entrada:** este sketch lee AIN0 contra AINCOM (single-ended), y
asume que ya le llega una señal **acondicionada** (amplificador de
instrumentación, ej. INA818, como quedó anotado en la comparativa) — el
ADS1256 por sí solo NO amplifica lo suficiente la salida cruda de un puente
de Wheatstone. Si todavía no tienes el amplificador armado, podés probar el
sketch igual conectando una fuente de voltaje conocida (ej. un divisor
resistivo) a AIN0 para verificar que el driver lee bien antes de meter la
celda real.

## 2. Software (Arduino IDE)

1. No hace falta instalar ninguna librería extra para el ADS1256 (usa
   `SPI.h`, que ya viene con el core de ESP32).
2. Abrir `test_ads1256.ino` como sketch independiente (misma estructura que
   los demás sketches de `Firmware/`).
3. Revisar las constantes de configuración al inicio del archivo
   (`ADS1256_VREF`, `ADS1256_PGA_CODE`/`ADS1256_PGA_GANANCIA`,
   `ADS1256_DRATE_CODE`) contra tu hardware real antes de cargar.
4. Cargar y abrir el Monitor Serie a **115200 baudios**.

## 3. Calibración (tara + masa patrón)

Al arrancar, si ya calibraste antes, el sketch carga la tara y el factor de
escala guardados en flash (NVS) — igual mecanismo que usa
`homing_absoluto.ino` para el cero del pivote.

Para calibrar desde cero (o recalibrar):

1. Con la celda **sin ninguna carga**, escribir `t` y Enter en el Monitor
   Serie. El sketch promedia 20 lecturas y guarda ese voltaje como tara.
2. Poner una **masa patrón conocida** (ej. una pesa de 5 kg) sobre la celda.
3. Escribir `k5.0` y Enter (reemplazando `5.0` por la masa real en kg). El
   sketch promedia 20 lecturas, calcula el delta de voltaje contra la tara y
   guarda el factor de escala (N/V) en flash.
4. Listo — la columna `force_N` de la salida ya refleja la calibración.

Para borrar la tara/calibración guardadas: escribir `r` y Enter.

**Mientras no hayas calibrado** (`calibrated=0` en la salida), la columna
`force_N` se imprime en 0.0 y **no debe tomarse como una lectura real** —
solo sirve para verificar que el ADC está respondiendo.

## 4. Qué esperar

Salida CSV: `raw_code,voltage_V,force_N,tared,calibrated`

- `raw_code`: código crudo de 24 bits con signo que entrega el ADC (rango
  aprox. ±8 388 607).
- `voltage_V`: `raw_code` convertido a voltios en la entrada del ADS1256,
  según el Vref y la ganancia configurados — **sin** restar la tara.
- `force_N`: `(voltage_V - tara) * factor_escala`, en Newtons. Solo válido
  si `calibrated=1`.
- `tared` / `calibrated`: 1/0 según si ya se hizo `t` / `k<masa>` (o se
  cargó una calibración guardada de flash).

Si ves el mensaje `ERROR: timeout esperando DRDY del ADS1256`, el sketch no
está recibiendo el pulso de "dato listo" — lo más común es un problema de
cableado (DRDY, CS, alimentación) o que el CLKIN del ADS1256 no está
oscilando (revisar que el cristal del breakout esté bien montado).

## 5. Siguiente paso

- Definir y armar el acondicionamiento analógico real (puente de Wheatstone
  + INA818) una vez que se cierre la elección de celda de carga (Pendientes
  S4, "Selección de sensor de fuerza del pylon" — sigue abierto).
- Diseñar la lectura multiplexada de los 6 canales de la AMTI compartiendo
  este mismo ADS1256 (Pendientes S4, sección AMTI) — implica rotar el
  registro MUX entre conversiones y sincronizar contra el DRDY de cada una,
  algo que este sketch todavía no hace (solo lee un canal fijo).
- Una vez con la celda real montada, validar la calibración con al menos 2-3
  masas patrón distintas (no solo una) para confirmar linealidad, en línea
  con el objetivo de validación cruzada trazable a ISO 7500-1.

## 6. Visor en tiempo real (Python)

Igual que con los sketches de IMU, hay un visor gráfico en
`visor_python/visor_ads1256.py` que lee el puerto serial y grafica el
voltaje crudo y la fuerza calibrada en vivo.

```
cd visor_python
pip install -r requirements.txt
python visor_ads1256.py --port COM5
```

El visor muestra si la lectura está tarada/calibrada (según las columnas
`tared`/`calibrated` de cada línea) y permite reenviar los comandos `t`,
`k<masa>` y `r` directo desde la ventana del gráfico (sin volver al Monitor
Serie del Arduino IDE), para no tener que andar cambiando de programa a
mitad de la calibración.

## 7. Pinout de referencia de los componentes

Verificado contra las hojas de datos oficiales de Texas Instruments (ver
fuentes al final). Esto complementa la tabla de la Secc. 1 (esa es la que
importa para cablear con el ESP32); acá está el pinout completo de cada
chip, útil si diseñan su propia placa o si necesitan mapear los pines de un
breakout/módulo a la función real del chip.

### 7.1 ADS1256 (chip "pelado", encapsulado SSOP-28)

| Pin | Nombre | Función |
|---|---|---|
| 1 | AVDD | Alimentación analógica |
| 2 | AGND | Tierra analógica |
| 3 | VREFN | Referencia negativa |
| 4 | VREFP | Referencia positiva |
| 5 | AINCOM | Entrada analógica común (usada como "AINN" en modo single-ended) |
| 6 | AIN0 | Entrada analógica 0 |
| 7 | AIN1 | Entrada analógica 1 |
| 8 | AIN2 | Entrada analógica 2 |
| 9 | AIN3 | Entrada analógica 3 |
| 10 | AIN4 | Entrada analógica 4 |
| 11 | AIN5 | Entrada analógica 5 |
| 12 | AIN6 | Entrada analógica 6 |
| 13 | AIN7 | Entrada analógica 7 |
| 14 | SYNC/PDWN | Sincronización / apagado (activo en LOW) |
| 15 | RESET | Reset (activo en LOW) |
| 16 | DVDD | Alimentación digital |
| 17 | DGND | Tierra digital |
| 18 | XTAL2 | Cristal (salida del oscilador) |
| 19 | XTAL1/CLKIN | Cristal (entrada) o reloj externo |
| 20 | CS | Chip select (activo en LOW) |
| 21 | DRDY | Dato listo (salida, activo en LOW) |
| 22 | DOUT | Salida de datos SPI (MISO) |
| 23 | DIN | Entrada de datos SPI (MOSI) |
| 24 | SCLK | Reloj SPI |
| 25 | D0/CLKOUT | GPIO 0 / salida de reloj |
| 26 | D1 | GPIO 1 |
| 27 | D2 | GPIO 2 |
| 28 | D3 | GPIO 3 |

Nota: AIN0-AIN7 y AINCOM son los 8 canales que se piensan compartir con la
celda de carga (AIN0, ya usado por este sketch) y los 6 canales de la AMTI
(AIN1-AIN6 quedarían libres para eso, ver Secc. 5).

**Si usan un módulo/breakout** (ej. Waveshare "High Precision AD/DA Board",
o el clon genérico vendido como "Teyleten Robot"/HiLetgo/JESSINIE — placa
roja de 24 bits/8 canales, mismo diseño de fábrica reempaquetado bajo varias
marcas) en vez del chip suelto: el módulo ya trae AVDD/DVDD, AGND/DGND,
VREFP/VREFN y el cristal de XTAL1/XTAL2 resueltos internamente, y expone
solo un subconjunto simplificado de pines en el header.

No existe un datasheet propio publicado por "Teyleten Robot" — es un
revendedor de este diseño genérico, no el fabricante del chip ni de la
placa. Confirmado cruzando la ficha de este mismo módulo bajo otras marcas
(Agarwal Electronics y HiLetgo, ver fuentes): el header trae **5V, GND,
SCLK, DIN, DOUT, CS, DRDY, PDWN** + los 8 canales analógicos `AIN0`...`AIN7`
— **sin** un pin RESET separado, y con una referencia de voltaje a bordo
(típico ADR03, 2.5V — coincide con `ADS1256_VREF` del sketch). Esos son los
pines que se cablearon en la Secc. 1, junto con el aviso de niveles lógicos
(el módulo es de 5V fijo, sin jumper a 3.3V en ninguna de las fichas
revisadas). **Si tu unidad física trae un silkscreen distinto, verificalo
contra las fotos del vendedor antes de energizar** — entre revendedores del
mismo diseño a veces cambia el rotulado, aunque el circuito sea idéntico.

### 7.2 INA818 (amplificador de instrumentación, 8 pines SOIC/VSSOP)

Es el amplificador propuesto en la comparativa de sensores para acondicionar
la salida cruda mV/V del puente de Wheatstone antes de entregarla al ADS1256
(ver nota de la Secc. 1). Todavía no está armado ni elegido en definitiva
(la celda de carga tampoco lo está), así que esto es la referencia para
cuando se arme el circuito.

| Pin | Nombre | Función |
|---|---|---|
| 1 | RG | Resistencia de ganancia (junto con el pin 8) |
| 2 | –IN | Entrada inversora |
| 3 | +IN | Entrada no inversora |
| 4 | –VS | Alimentación negativa |
| 5 | REF | Entrada de referencia (offset de salida) |
| 6 | OUT | Salida |
| 7 | +VS | Alimentación positiva |
| 8 | RG | Resistencia de ganancia (junto con el pin 1) |

- **Ganancia:** `G = 1 + (50 kΩ / RG)`. Ej.: RG=1kΩ -> G≈51; RG=499Ω -> G≈101.
  El valor exacto depende de cuánto entregue el puente de la celda elegida
  (mV/V) y cuánto rango de entrada quieran usarle al ADS1256 — todavía
  pendiente de calcular hasta cerrar la celda.
- **Alimentación:** acepta single-supply 4.5-36V o dual ±2.25-18V. Con el
  ESP32 a 3.3V, probablemente convenga alimentar el INA818 con una fuente
  separada de 5V (no directo del ESP32) para tener margen de swing en la
  salida.
- **REF (pin 5):** en single-supply, TI recomienda llevarlo a un nivel de
  offset preciso de media alimentación (ej. 2.5V con fuente de 5V) mediante
  una fuente de bajo-impedancia dedicada (ej. un divisor resistivo con buffer,
  o un IC de referencia) — **no** dejarlo flotando ni conectarlo directo a
  VREFP del ADS1256 (esa referencia debe quedar limpia para el propio ADC).
  Esto centra la salida en el "cero" de fuerza y deja rango simétrico para
  compresión/tracción si la celda mide en ambos sentidos.
- **Salida (pin 6) -> AIN0 del ADS1256** (canal ya configurado en el sketch).

### 7.3 Celda de carga genérica (puente de Wheatstone, 4 hilos)

Todavía sin celda final elegida (ver Pendientes S4), pero el código de
colores de 4 hilos es el mismo para casi todas las candidatas de la
comparativa (S-type, donut, strain-gauge propia):

| Color (convención más común) | Función |
|---|---|
| Rojo | Excitación + (E+ / EXC+) |
| Negro | Excitación – (E– / EXC–) |
| Verde | Señal + (S+ / SIG+) |
| Blanco | Señal – (S– / SIG–) |

**Importante:** este código de colores NO es 100% universal entre
fabricantes (algunos usan amarillo/azul para la señal, por ejemplo) —
verificar siempre contra la hoja de datos de la celda que se termine
eligiendo. E+/E– van a la excitación del puente (alimentación de la galga,
típicamente 5-10V regulados y estables); S+/S– son la salida diferencial de
pocos mV que entra a IN+/IN– del INA818.

### Fuentes consultadas

- [ADS1256 datasheet (SBAS288) — Texas Instruments](https://www.ti.com/lit/ds/symlink/ads1256.pdf)
- [INA818 datasheet — Texas Instruments](https://www.ti.com/lit/ds/symlink/ina818.pdf)
- [Teyleten Robot ADS1256 24-bit 8-Channel ADC Module — listado en Amazon](https://www.amazon.com/Teyleten-Robot-8-Channel-High-Precision-Acquisition/dp/B0F4DPM9J1) (sin datasheet propio publicado; mismo diseño que las fuentes siguientes)
- [ADS1256 24-Bit ADC Module — ficha técnica, Agarwal Electronics](https://www.agarwalelectronics.com/product/7580/) (mismo diseño de módulo, header/pines confirmados)
- [HiLetgo ADS1256 5V 8 Channel 24 Bit ADC Module — manual, Manuals+](https://manuals.plus/asin/B09KGXC44Q) (mismo diseño de módulo, header/pines confirmados por segunda fuente independiente)

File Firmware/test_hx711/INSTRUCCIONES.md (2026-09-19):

# Driver de prueba HX711 — celda de carga (ESP32)

Sketch de prueba para el módulo HX711 (ADC de 24 bits + amplificador
integrado, dedicado a celdas de carga). Es una vía **en paralelo** al
[driver del ADS1256](../test_ads1256/INSTRUCCIONES.md), no un reemplazo: el
ADS1256 sigue siendo el ADC elegido a largo plazo para LIBRA (8 canales, para
compartir después con la plataforma AMTI — ver la
[comparativa de sensores](../../Estado-del-arte/SENSORES%20DE%20FUERZA/PYLON/Comparativa-Sensores-Fuerza-Axial-Pylon.md)).

**Por qué probar el HX711 ahora:** sirve para verificar rápido si la celda de
carga y su cableado están bien, aislado del ADS1256 — útil mientras se sigue
diagnosticando el ruido tipo diente de sierra que aparece con ese driver. Si
con el HX711 la lectura sale limpia, el problema está más del lado del
ADS1256/su cableado (o de la fuente/tierra compartida) que de la celda en sí.

## 1. Conexionado

Módulo HX711 genérico (la placa chiquita con capacitores que casi siempre se
vende junto con celdas de carga tipo "barra"/"balanza"):

| Módulo (silkscreen) | ESP32 | Notas |
|---|---|---|
| VCC / VDD | 3.3V | ver aviso de niveles lógicos abajo — **no** usar 5V por ahora |
| GND | GND | común con la celda y el resto del circuito |
| DT (DOUT / DAT) | GPIO32 | salida de datos del módulo → entrada del ESP32 |
| SCK (CLK) | GPIO33 | reloj → salida del ESP32 hacia el módulo |
| E+ (rojo) | — | ya conectado internamente al VCC del módulo (excitación) |
| E- (negro) | — | ya conectado internamente al GND del módulo |
| A+ (verde) | señal + de la celda | canal A, ganancia 128 por defecto |
| A- (blanco) | señal − de la celda | |
| B+ / B- | libres | canal B, ganancia fija en 32 — para una segunda celda, no se usa acá |

### ⚠️ Por qué este módulo NO necesita level shifter (a diferencia del ADS1256)

El chip HX711 acepta alimentación (VCC) entre **2.6V y 5.5V**. Alimentándolo
con el 3.3V del propio ESP32 (en vez de una fuente de 5V separada, como sí
hace falta con el módulo ADS1256 genérico — ver su INSTRUCCIONES.md), sus
pines digitales (DT de salida, SCK de entrada) quedan directamente en lógica
de 3.3V: compatibles con el ESP32 **sin ningún conversor de nivel lógico**.

Contrapartida: la excitación de la celda (E+/E−) también queda a 3.3V en vez
de 5V (el módulo ata E+ al mismo VCC), así que la señal de la celda (mV/V)
sale algo más chica que alimentando a 5V. Para una prueba/comparación rápida
no debería ser problema.

Si más adelante hace falta el máximo rango alimentando a 5V, ahí sí hay que
volver a cuidar los niveles lógicos: DT saldría en lógica de 5V (el ESP32 no
la tolera) y SCK, siendo entrada del HX711, necesitaría ~0.7×5V=3.5V para
registrar HIGH de forma confiable (el 3.3V del ESP32 queda justo por debajo)
— por eso conviene arrancar con 3.3V y no con 5V.

**Tasa de muestreo:** fija por hardware según el pin RATE del módulo — la
gran mayoría de los breakouts genéricos lo dejan fijo en **10 SPS** (algunos
traen un puente/jumper para 80 SPS). No se controla desde este sketch.

## 2. Software (Arduino IDE)

1. Instalar la librería **"HX711" de Bogdan Necula**
   ([github.com/bogde/HX711](https://github.com/bogde/HX711)) desde el
   Library Manager: Herramientas > Administrar Bibliotecas > buscar `HX711` >
   instalar la de Bogdan Necula (a diferencia del ADS1256, acá sí hay una
   librería estándar y muy usada — no hace falta implementar el protocolo a mano).
2. Abrir `test_hx711.ino` como sketch independiente (misma estructura que los
   demás sketches de `Firmware/`).
3. Revisar los pines (`PIN_HX711_DT`, `PIN_HX711_SCK`) contra tu cableado real
   antes de cargar.
4. Cargar y abrir el Monitor Serie a **115200 baudios**.

## 3. Calibración (tara + masa patrón)

Mismo esquema que `test_ads1256.ino` — al arrancar, si ya calibraste antes,
el sketch carga la tara y el factor de escala guardados en flash (NVS).

Para calibrar desde cero (o recalibrar):

1. Con la celda **sin ninguna carga**, escribir `t` y Enter en el Monitor
   Serie. El sketch promedia 20 lecturas y guarda esa cuenta cruda como tara.
2. Poner una **masa patrón conocida** (ej. una pesa de 5 kg) sobre la celda.
3. Escribir `k5.0` y Enter (reemplazando `5.0` por la masa real en kg). El
   sketch promedia 20 lecturas, calcula el delta de cuentas contra la tara y
   guarda el factor de escala (N/cuenta) en flash.
4. Listo — la columna `force_N` de la salida ya refleja la calibración.

Para borrar la tara/calibración guardadas: escribir `r` y Enter.

**Mientras no hayas calibrado** (`calibrated=0` en la salida), la columna
`force_N` se imprime en 0.0 y **no debe tomarse como una lectura real** —
solo sirve para verificar que el HX711 está respondiendo.

## 4. Qué esperar

Salida CSV: `raw_code,force_N,tared,calibrated`

- `raw_code`: cuenta cruda de 24 bits con signo que entrega el HX711 (SIN
  restar la tara). A diferencia del ADS1256, el HX711 no tiene una referencia
  de voltaje bien definida y pública, así que **no** se convierte a voltios
  — se calibra directo de cuentas crudas a Newtons.
- `force_N`: `(raw_code - tara) * factor_escala`, en Newtons. Solo válido si
  `calibrated=1`.
- `tared` / `calibrated`: 1/0 según si ya se hizo `t` / `k<masa>` (o se cargó
  una calibración guardada de flash).

Si ves el mensaje `ERROR: timeout esperando datos del HX711`, el sketch no
está recibiendo respuesta del módulo — lo más común es un problema de
alimentación (VCC/GND) o de cableado de DT/SCK.

## 5. Comparación con el ADS1256

Si el HX711 da una lectura limpia (sin el diente de sierra que se vio con el
ADS1256) usando la **misma celda y el mismo cableado físico de la celda**
(solo cambiando el ADC), es una señal fuerte de que el problema está en el
lado del ADS1256/su alimentación/su tierra — no en la celda ni en su
cableado. Si el HX711 **también** sale ruidoso, el problema es más probable
que esté en la celda, su cableado (EXC+/EXC-/SIG+/SIG-) o la fuente que la
alimenta, independiente del ADC usado.

## 6. Visor en tiempo real (Python)

Igual que con el ADS1256, hay un visor gráfico en
`visor_python/visor_hx711.py` que lee el puerto serial y grafica las cuentas
crudas y la fuerza calibrada en vivo, con una caja de texto para mandar los
comandos `t`, `k<masa>` y `r` sin volver al Monitor Serie.

```
cd visor_python
pip install -r requirements.txt
python visor_hx711.py --port COM5
```

## 7. Registro a CSV (Python)

Para grabar una sesión de pesaje a un archivo CSV (sin gráficos), usar
`visor_python/log_csv_hx711.py` — mismo patrón que `log_csv_ads1256.py`.
Antes de grabar, calibrar una vez con el Monitor Serie o `visor_hx711.py`
(queda guardado en flash):

```
cd visor_python
python log_csv_hx711.py --port COM7 --duracion 30
```

## 8. Siguiente paso

- Una vez confirmado si el HX711 reproduce o no el ruido visto con el
  ADS1256 (ver Secc. 5), volver al diagnóstico de `test_ads1256/` con esa
  información: si el HX711 sale limpio, revisar alimentación/tierra del
  módulo ADS1256 y del level shifter; si también sale ruidoso, revisar la
  celda y su cableado físico (EXC+/EXC-/SIG+/SIG-) antes que el ADC.
- El HX711 es un ADC dedicado de 1-2 canales — **no** sirve para compartirlo
  después con los 6 canales de la AMTI (a diferencia del ADS1256, que sí
  tiene 8 canales para eso). Este sketch es solo para pruebas/diagnóstico,
  no reemplaza al ADS1256 en la arquitectura final de LIBRA.

## 9. Pinout completo del chip HX711 (para diseño de PCB propia)

Si en vez del módulo genérico vas a diseñar tu propia placa con el chip HX711
"pelado" (encapsulado SOP-16L, 16 pines), esto es el pinout completo
verificado contra la hoja de datos oficial de Avia Semiconductor (fabricante
del chip — ver fuente al final):

| Pin | Nombre | Función (hoja de datos) | Qué conectar en tu PCB |
|---|---|---|---|
| 1 | VSUP | Alimentación del regulador interno, 2.7-5.5V | Ver "regulador interno" abajo — en el uso simple, unir a AVDD/DVDD |
| 2 | BASE | Salida de control del regulador analógico interno (transistor PNP externo) | NC (sin conectar) si no usás el regulador interno |
| 3 | AVDD | Alimentación analógica, 2.6-5.5V | Tu fuente de 3.3V (misma que DVDD si no usás el regulador — igual que el módulo genérico) |
| 4 | VFB | Entrada de realimentación del regulador | A AGND si no usás el regulador interno |
| 5 | AGND | Tierra analógica | GND — **único pin de tierra del chip**, no hay DGND separado en este encapsulado |
| 6 | VBG | Salida de bypass de la referencia interna | Capacitor de 0.1uF a AGND, lo más cerca posible del pin |
| 7 | INA- | Entrada negativa, canal A | Señal− de la celda de carga (canal usado en `test_hx711.ino`) |
| 8 | INA+ | Entrada positiva, canal A | Señal+ de la celda de carga |
| 9 | INB- | Entrada negativa, canal B | Libre, o ruteala a un header por si más adelante hace falta una 2da celda |
| 10 | INB+ | Entrada positiva, canal B | Libre (ganancia fija en 32, no configurable) |
| 11 | PD_SCK | Reloj serie + control de power-down (activo en alto) | GPIO del ESP32 (salida) — GPIO33 en el sketch actual |
| 12 | DOUT | Salida de datos serie | GPIO del ESP32 (entrada) — GPIO32 en el sketch actual |
| 13 | XO | Salida del oscilador a cristal | NC si usás el oscilador interno (ver nota) |
| 14 | XI | Entrada del oscilador a cristal, o reloj externo. 0 = usa el oscilador interno | A AGND para usar el oscilador interno (recomendado, no hace falta cristal) |
| 15 | RATE | Selección de tasa de datos: 0=10Hz, 1=80Hz | A AGND para 10Hz (recomendado para una celda de carga estática/cuasi-estática) |
| 16 | DVDD | Alimentación digital, 2.6-5.5V | Misma fuente de 3.3V que AVDD |

### Notas para el diseño de la PCB

- **Regulador interno:** el HX711 trae un LDO interno (VSUP + BASE + VFB + un
  transistor PNP externo tipo S8550) para generar una AVDD estable a partir
  de una fuente más ruidosa. Para un prototipo simple como el que ya
  validaste con el módulo genérico **no hace falta usarlo**: alimentás AVDD y
  DVDD directo con 3.3V, dejás BASE sin conectar y VFB a AGND — así vienen
  armados la mayoría de los módulos breakout genéricos.
- **Una sola tierra:** a diferencia del ADS1256 (AGND y DGND separados en sus
  28 pines), el HX711 solo tiene un pin de tierra (AGND, pin 5) — analógico y
  digital comparten la misma referencia en este chip.
- **Oscilador:** no hace falta cristal externo — atando XI a AGND (y dejando
  XO sin conectar) el chip usa su oscilador interno, igual que los módulos
  genéricos.
- **Excitación de la celda (medición ratiométrica):** conectá el EXC+ de la
  celda de carga directo a AVDD (la misma alimentación del chip, no una
  fuente aparte) y EXC- a AGND. Esto es clave: como la referencia interna del
  ADC deriva de AVDD, cualquier variación en la alimentación afecta por igual
  a la excitación de la celda y a la referencia — se cancela y no mete error.
  Por eso el HX711 no necesita una fuente de excitación regulada aparte, a
  diferencia de un ADC con referencia fija como el ADS1256.
- **Desacople:** capacitor cerámico de 0.1uF bien cerca de AVDD/DVDD a AGND,
  más uno de mayor valor (ej. 10uF) en la entrada de alimentación general —
  práctica estándar de buen diseño aunque el datasheet no lo detalle para
  este modo simplificado.
- **Filtro en las entradas (opcional, recomendado):** un filtro RC chico (ej.
  100Ω en serie + 100nF entre INA+/INA- a tierra) ayuda a rechazar ruido de
  RF/EMI captado por cables largos hacia la celda — varios diseños de
  referencia lo incluyen.
- **Encapsulado:** SOP-16L (16 pines, montaje superficial). Para el footprint
  exacto (dimensiones, paso entre pines) revisar el dibujo mecánico en la
  hoja de datos completa (fuente abajo), o buscar una librería ya hecha para
  KiCad/Eagle/Altium — es un chip muy común, probablemente ya exista un
  footprint listo.

### Fuentes consultadas

- [HX711 24-Bit ADC — Pinout, Datasheet, Interfacing Examples](https://microcontrollerslab.com/hx711-adc-weigh-scales/) (rango de alimentación 2.6-5.5V, ganancias por canal, pin RATE 10/80 SPS)
- [GroundStudio HX711 module datasheet](https://mm.digikey.com/Volume0/opasdata/d220001/medias/docus/5864/HX711%20Module.PDF) (etiquetas del breakout: VCC/GND/DAT/CLK/E+/E-/A+/A-/B+/B-, rango de alimentación 2.7-5.5V)
- [HX711 Arduino Library — Bogdan Necula, GitHub](https://github.com/bogde/HX711) (librería usada en este sketch: begin, wait_ready_timeout, read, read_average, tare, set_scale)
- [HX711 datasheet — Avia Semiconductor (mirror SparkFun)](https://cdn.sparkfun.com/datasheets/Sensors/ForceFlex/hx711_english.pdf) (pinout completo del chip SOP-16L, circuito de aplicacion, regulador interno)

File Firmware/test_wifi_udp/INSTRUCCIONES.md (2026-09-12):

# Test envío de datos por WiFi (UDP), sin cable (ESP32)

Es el mismo MPU6050 y la misma lógica de `test_mpu6050.ino` (filtro complementario propio para roll/pitch, más `yaw_solo_giro` para ver el drift) — lo único que cambia es el transporte: en vez de mandar el CSV por el cable USB (Serial), el ESP32 lo manda por WiFi como paquetes UDP directo a la IP de la PC. Es la forma más simple de sacar el cable de en medio: no requiere instalar ningún servidor/broker, solo que el ESP32 y la PC estén en la misma red WiFi (no hace falta internet real, basta la red local del laboratorio o del celular en hotspot).

## 1. Conexionado

Igual que `test_mpu6050.ino` — ver esa carpeta. El ESP32 sigue necesitando alimentación (USB o una fuente de 5V aparte); lo que ya no necesita es que el cable USB esté conectado a la PC del visor mientras mide.

## 2. Configurar el sketch antes de cargar

Editar estas 3 líneas al inicio de `test_wifi_udp.ino`:

```cpp
const char* WIFI_SSID     = "TU_RED_WIFI";
const char* WIFI_PASSWORD = "TU_PASSWORD";
const char* PC_IP         = "192.168.1.100";
```

`PC_IP` es la IP local de la laptop que va a correr el visor **en esa misma red WiFi** — el propio `visor_wifi_udp.py` la imprime apenas lo corres (sección 4), para copiarla aquí. Si cambias de red (de casa al laboratorio, por ejemplo) hay que volver a cargar el sketch con la IP nueva, porque las IPs locales suelen cambiar de red a red.

## 3. Software (Arduino IDE)

1. Mismas librerías que `test_mpu6050.ino`: **Adafruit MPU6050**, **Adafruit Unified Sensor**, **Adafruit BusIO**.
2. `WiFi.h` y `WiFiUdp.h` ya vienen incluidas en el core de ESP32 — no hay que instalar nada aparte, solo tener seleccionada una placa ESP32 en Herramientas > Placa.
3. Cargar y abrir el Monitor Serie a 115200 baudios — sigue imprimiendo el mismo CSV por Serial además de mandarlo por WiFi, útil para confirmar que el sensor funciona aunque el visor de WiFi todavía no reciba nada.

## 4. Visor en tiempo real (Python)

```
cd visor_python
pip install -r requirements.txt
python visor_wifi_udp.py
```

Al arrancar, imprime la IP local de tu PC — cópiala en `PC_IP` del sketch (paso 2) antes de cargarlo, si todavía no lo hiciste. Por defecto escucha en el puerto UDP 4210 (igual que `UDP_PORT` en el `.ino`); si lo cambias en uno, cámbialo en el otro.

El gráfico es idéntico al de `visor_mpu6050.py` (roll/pitch/yaw arriba, aceleración cruda al medio, giro crudo abajo) — el botón "Zero / Reset" sigue siendo solo un offset visual, no reinicia el drift real que se sigue acumulando dentro del ESP32.

## 5. Qué esperar / cómo depurar si no llega nada

- Si el Monitor Serie muestra el CSV pero el visor de Python no dibuja nada: lo más probable es la IP (verifica que `PC_IP` en el sketch sea exactamente la que imprimió el visor) o el **firewall de Windows** bloqueando el puerto UDP 4210 entrante — la primera vez que corres `visor_wifi_udp.py` puede aparecer un aviso de firewall, hay que permitir el acceso.
- Confirma que el ESP32 y la laptop estén en la **misma red** (mismo WiFi, no uno en WiFi y otro compartiendo datos móviles, y ojo con routers que aíslan clientes entre sí — "AP/client isolation" — algunos WiFi de universidades o de celulares en hotspot lo activan por defecto).
- Si el WiFi se cae a medias, el sketch reintenta conectarse solo (ver `loop()`), pero es bloqueante mientras reconecta — los datos de esos segundos se pierden, no se guardan en cola.

## 6. Limitación de UDP (léelo antes de confiar en esto para el registro final)

UDP no confirma entrega ni garantiza orden: si un paquete se pierde por interferencia de WiFi, simplemente no llega — no hay reintento automático ni error visible. Para *ver* los datos en vivo en el banco de pruebas esto es aceptable (mismo riesgo que ya existe con Serial si se satura el buffer), pero **no es la base para el registro/almacenamiento sincronizado que pide el objetivo de Software del proyecto** (`README.md`). Si más adelante hace falta:

- Confirmación de entrega o mandar comandos de vuelta al ESP32 → considerar TCP o WebSocket.
- Varios ESP32/sensores publicando a la vez de forma ordenada, con reconexión automática robusta → considerar **MQTT** (broker tipo Mosquitto corriendo en la misma PC o en un Raspberry Pi del laboratorio, librería `PubSubClient` en el ESP32, `paho-mqtt` en Python) — el payload CSV que ya usas no cambiaría, solo el transporte.

Este sketch es un punto de partida para probar el concepto de "sensor sin cable", no el diseño final de adquisición sincronizada multi-sensor.

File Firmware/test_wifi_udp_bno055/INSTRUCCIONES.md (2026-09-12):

# Test envío de datos por WiFi (UDP) — BNO055 DFRobot (ESP32)

Versión para BNO055 de `Firmware/test_wifi_udp/` (esa carpeta usa el MPU6050 con la librería Adafruit). Esta usa la librería **`DFRobot_BNO055`** — la del módulo Fermion (SEN0374) que estás usando, no `Adafruit_BNO055` como `test_bno055.ino` — y mantiene el mismo cero absoluto persistente en flash que ya tenías (comandos `z`/`c`), ahora también disponible por WiFi.

## 1. Conexionado

Idéntico a `test_bno055.ino` (ver esa carpeta): I2C, `BNO055 VCC→3V3, GND→GND, SDA→GPIO21, SCL→GPIO22`, dirección por defecto `0x28` (pad I2C_ADDR del módulo sin puentear).

## 2. Configurar el sketch antes de cargar

Editar al inicio de `test_wifi_udp_bno055.ino`:

```cpp
const char* WIFI_SSID     = "TU_RED_WIFI";
const char* WIFI_PASSWORD = "TU_PASSWORD";
const char* PC_IP         = "192.168.1.100";
```

`PC_IP` es la IP local de la laptop que corre el visor — `visor_wifi_bno055.py` la imprime al arrancar (sección 4). Usa el puerto UDP **4211** (distinto del ejemplo del MPU6050, que usa 4210) por si algún día corres los dos sketches de WiFi a la vez sin que se pisen.

## 3. Software (Arduino IDE)

1. Instalar la librería **DFRobot_BNO055**: Sketch > Include Library > Add .ZIP Library... y seleccionar el `SEN0374_bno055intelligent9axissensor_library_v1.zip` que ya tienes (o copiar la carpeta `DFRobot_BNO055-master` a tu carpeta `Arduino/libraries/`, renombrada a `DFRobot_BNO055`).
2. `WiFi.h`/`WiFiUdp.h` ya vienen en el core de ESP32 — no instalar nada aparte.
3. Cargar y abrir el Monitor Serie a 115200 baudios — sigue imprimiendo el mismo texto por Serial como respaldo, útil para confirmar que el sensor responde aunque el visor de WiFi no reciba nada todavía.

## 4. Visor en tiempo real (Python)

```
cd visor_python
pip install -r requirements.txt
python visor_wifi_bno055.py
```

Al arrancar imprime tu IP local — cópiala en `PC_IP` (paso 2) antes de cargar el sketch. El gráfico es igual al de `visor_imu.py` (heading/roll/pitch arriba, aceleración lineal en m/s² abajo, estado de calibración en el título) y tiene los mismos 3 botones:

- **"Zero grafico (local)"**: offset solo visual en este script, no toca el ESP32.
- **"Cero absoluto (flash)"**: manda el comando `z` — pero ahora **por WiFi** en vez de por el cable. El visor recién puede mandarlo después de recibir al menos un paquete del ESP32 (así descubre su IP solo, sin que la configures a mano).
- **"Borrar cero (flash)"**: manda `c` por WiFi, igual que el anterior.

## 5. Diferencias de unidades frente a `test_bno055.ino` (Adafruit) — importante si comparas datos

- La librería DFRobot da la aceleración lineal en **mg** (miligravedad); el sketch la convierte a **m/s²** (factor 9.80665/1000) para que sea comparable directo con `test_bno055.ino` y `test_mpu6050.ino`.
- `getEul()` ya da heading/roll/pitch en grados, igual que Adafruit.
- Esta librería **no expone un método público de temperatura** (a diferencia de `Adafruit_BNO055::getTemp()`), así que este sketch no reporta temperatura — es la única diferencia real de contenido frente a `test_bno055.ino`.

## 6. Qué esperar / cómo depurar si no llega nada

Mismos puntos que `test_wifi_udp/INSTRUCCIONES.md` (MPU6050): revisar que `PC_IP` sea exactamente la que imprimió el visor, revisar el firewall de Windows la primera vez que corres el script (puede pedir permiso para el puerto UDP), y confirmar que ESP32 y laptop estén en la misma red WiFi (sin aislamiento de clientes entre sí).

## 7. Limitación de UDP (léelo antes de usar esto como registro final)

Igual que con el MPU6050: UDP no confirma entrega ni garantiza orden — un paquete perdido por interferencia simplemente no llega, sin aviso. Sirve para *ver* los datos en vivo y probar el cero absoluto por WiFi, pero **no es la base para el registro/almacenamiento sincronizado multi-sensor** que pide el objetivo de Software del proyecto (`README.md`). El siguiente paso natural si hace falta más robustez (varios sensores/ESP32 a la vez, reconexión automática, confirmación de entrega) es MQTT — el payload de texto que ya usas no cambiaría, solo el transporte.

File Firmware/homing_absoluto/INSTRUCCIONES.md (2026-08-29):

# Homing / cero absoluto persistente (MPU6050)

Prototipo para probar la idea de usar el acelerómetro (referencia de gravedad) para establecer un **cero absoluto del pivote de flexo-extensión**, y que ese cero sobreviva a apagar/encender el sistema (se guarda en la memoria flash del ESP32, no en RAM).

## Conexionado

Igual que `test_mpu6050.ino`: VCC→3V3, GND→GND, SDA→GPIO21, SCL→GPIO22, AD0→GND (dirección 0x68).

## Librerías

Adafruit MPU6050, Adafruit Unified Sensor, Adafruit BusIO. `Preferences.h` (usada para guardar el cero en flash) ya viene incluida en el core de ESP32, no hay que instalar nada extra.

## Cómo probarlo

1. Cargar el sketch, abrir el Monitor Serie a 115200 baudios.
2. Poner el pivote/pylon en la posición física que quieres que sea "cero grados" (por ejemplo, perfectamente vertical) y mantenerlo quieto.
3. Escribir **`z`** y Enter en el Monitor Serie — el sketch promedia ~1 s de lecturas del acelerómetro y guarda ese ángulo como el cero absoluto en flash.
4. Mueve el pivote: la columna `roll_abs`/`pitch_abs` ahora reporta el ángulo **relativo a esa posición de referencia**, no un valor arbitrario.
5. **Apaga y vuelve a encender el ESP32** (o presiona reset): al arrancar, el mensaje debería decir "Cero absoluto cargado de la memoria flash..." con los mismos valores — confirma que el cero sobrevive al reinicio, que es el problema que estábamos resolviendo.
6. Escribir **`c`** y Enter para borrar el cero guardado y volver a "sin calibrar".

## Qué SÍ resuelve y qué NO

- **Sí resuelve:** referencia de posición absoluta para el eje de rotación (flexo-extensión), siempre que el "cero mecánico" corresponda a una orientación reconocible respecto a la gravedad, y que se pueda hacer un homing quieto al inicio de cada sesión de ensayo.
- **No resuelve:** el eje de traslación (husillo/riel) — ese sigue necesitando un encoder absoluto o un switch de home físico, como quedó anotado en `Reportes-Semanales/S3/Pendientes.md`.
- Es una rutina de homing puntual (al iniciar sesión), no una medición continua — durante el movimiento real el acelerómetro mezcla gravedad con aceleración dinámica y no sirve para esto.

## Portar esto al BNO055

La parte de guardar/cargar el cero en flash (`establecerZeroActual`, `guardarZeroEnFlash`, `cargarZeroDesdeFlash`) es igual para cualquier sensor — solo cambiarías de dónde sale `roll`/`pitch` (en el BNO055 vendría directo de `VECTOR_EULER` en vez del filtro complementario). Puedo armar esa versión si les resulta mejor opción que el MPU6050 para esto.

## Visor + control en Python

`visor_python/visor_homing.py` no es solo un visor — tiene dos botones que mandan de verdad los comandos `z`/`c` por Serial, así no necesitas escribirlos a mano en el Monitor Serie de Arduino:

```
cd visor_python
pip install -r requirements.txt
python visor_homing.py --port COM5
```

- **"Establecer cero (z)"**: manda `z` al ESP32 — mantén el pivote quieto en la posición de referencia antes de presionarlo, porque el ESP32 va a promediar ~1 s de lecturas del acelerómetro justo después.
- **"Borrar cero (c)"**: manda `c`, borra el cero guardado en flash.
- Panel superior: `roll_abs`/`pitch_abs` (relativos al cero guardado — esto es lo que te interesa para el ensayo).
- Panel inferior: `roll`/`pitch` crudos del filtro, sin restar el cero, para comparar.
- El título de la ventana indica si ya hay un cero absoluto guardado en flash o no.

Los mensajes de arranque/calibración/homing del ESP32 (que no son líneas CSV) se imprimen en la consola donde corres el script, no en el gráfico.

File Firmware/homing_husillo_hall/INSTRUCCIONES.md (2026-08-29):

# Homing del eje del motor con imán + sensor Hall

Pieza física + firmware para dar al motor paso a paso del husillo un **cero repetible y preciso**, sin goniómetro y sin depender de contar pasos (que se puede perder si el motor patina). Está inspirado directamente en el patrón "mastering con marca física" e "índice magnético" que quedó documentado en `Estado-del-arte/REFERENCIA DE POSICION ABSOLUTA/Arquitecturas-Referencia-Absoluta-sin-Goniometro.md`.

## Qué SÍ resuelve y qué NO (importante, leer antes de armarlo)

Esto da el cero **del eje del motor**, una vez por vuelta — repetible con precisión sub-paso. **No** te dice por sí solo en qué vuelta estás dentro de todo el recorrido del riel (el husillo da muchas vueltas para mover la plataforma de un extremo a otro). Para el cero absoluto de **todo el recorrido**, esto se combina con un límite físico en el carro/riel (switch mecánico, óptico o Hall — ver la comparativa de arquitecturas ya guardada): primero se lleva el carro hasta ese extremo (grueso), y después se usa este índice magnético del eje para afinar el punto exacto de parada (fino). Si quieren, arme también esa versión combinada — este sketch cubre la parte del eje del motor, que es lo que pediste.

A diferencia del homing con acelerómetro (`homing_absoluto.ino`), **este no necesita guardarse en memoria flash** — se vuelve a hacer en cada encendido, exactamente como hace una impresora 3D o una CNC al prenderse. No es una limitación, es cómo funciona este tipo de homing (el evento físico —encontrar el imán— está siempre disponible, no depende de que un humano lo confirme).

## Pieza física a imprimir

Un collarín/disco que se monta en el eje del motor:

- **Diámetro del eje**: mídelo con calibre (en NEMA17 suele ser 5 mm, pero verifícalo — no lo asumas).
- **Cuerpo del collarín**: diámetro exterior ~15–20 mm, espesor ~5–6 mm, con un agujero central prisionero mediante un tornillo M3 perpendicular al eje (permite reajustar el ángulo si el homing sale desalineado, sin tener que reimprimir la pieza).
- **Cavidad para el imán**: un bolsillo cerca del borde exterior del disco, dimensionado para un **imán de neodimio pequeño** (común y barato: ~4 mm de diámetro × 2 mm de espesor, se consigue en cualquier tienda de electrónica/hobby). Orientar el imán con el polo hacia afuera (hacia donde va a pasar el sensor).
- **Soporte del sensor**: un pequeño bracket atornillado al chasis del motor (o impreso también) que sostenga el sensor Hall a 2–4 mm del disco, alineado en el radio donde pasa el imán.

Si prefieren, puedo armarles el diseño paramétrico en OpenSCAD (fácil de ajustar medidas y volver a exportar STL) — solo dime el diámetro real del eje y confirmamos.

## Sensor y cableado

- **Sensor Hall digital** (tipo interruptor, ej. A3144 o similar — 3 pines: VCC, GND, OUT).
- VCC → 3V3 (o 5V si tu módulo específico lo requiere), GND → GND, OUT → `HALL_PIN` (GPIO34 en el sketch, con pull-up interno activado — `INPUT_PULLUP`). La salida es de colector abierto: se activa en BAJO cuando el imán está cerca, que es lo que asume el código.
- Los pines `STEP_PIN`/`DIR_PIN`/`ENABLE_PIN` del sketch son genéricos para cualquier driver STEP/DIR (A4988, DRV8825, TMC2209) — ajústalos a como esté cableado tu driver real.

## Cómo funciona el homing (dos etapas, igual que una CNC)

1. **Aproximación rápida**: el motor gira hasta el primer disparo del sensor.
2. **Retroceso** unos pasos.
3. **Aproximación lenta**: se vuelve a acercar despacio al mismo punto, dando un disparo mucho más repetible y preciso que con una sola pasada rápida (la velocidad afecta la precisión del punto de disparo — por eso CNC/impresoras 3D siempre hacen esto en dos tiempos).
4. Se fija `posicionPasos = 0` en ese punto.

Comandos por Serial: `h` para re-homear manualmente, `p` para imprimir la posición actual en pasos.

## Antes de correrlo en el simulador real

Hay un límite de seguridad (`MAX_PASOS_BUSQUEDA`) para que el motor no gire indefinidamente si el sensor o el imán fallan, pero **no reemplaza un límite mecánico real** — prueben primero con el motor desacoplado del husillo (girando libre) para confirmar que el sensor dispara de forma consistente, antes de conectarlo al mecanismo real donde un giro descontrolado podría chocar contra algo.

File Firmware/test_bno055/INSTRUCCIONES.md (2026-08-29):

# Test IMU BNO055 (ESP32)

Sketch mínimo para verificar que el BNO055 comunica por I2C y entrega datos coherentes, antes de decidir si se integra al simulador (ver comparativa de IMU en `Estado-del-arte/`).

## 1. Conexionado

| BNO055 | ESP32 |
|---|---|
| VIN | 3V3 |
| GND | GND |
| SDA | GPIO21 |
| SCL | GPIO22 |
| ADR | GND (dirección 0x28, la que usa el sketch por defecto) |
| RST | sin conectar |

Si el módulo específico trae otros pines de I2C por defecto, ajustar `Wire.begin(21, 22)` en el sketch.

## 2. Software (Arduino IDE)

1. Instalar el core de ESP32 en el Arduino IDE (Preferencias → URLs de gestor de tarjetas adicionales) si aún no está.
2. Administrador de bibliotecas → instalar **Adafruit BNO055** y **Adafruit Unified Sensor** (esta última es dependencia de la primera).
3. Abrir `test_bno055.ino`, seleccionar la placa ESP32 correspondiente y el puerto COM.
4. Cargar el sketch y abrir el Monitor Serie a **115200 baudios**.

## 3. Qué esperar

- Al iniciar: `BNO055 detectado correctamente.` Si en cambio aparece el mensaje de error, revisar alimentación, cableado SDA/SCL y dirección I2C (multímetro o un sketch de escaneo I2C si hace falta).
- Cada 200 ms se imprime una línea con:
  - **Calib[sys,gyro,accel,mag]**: cada valor va de 0 (sin calibrar) a 3 (calibración completa). El BNO055 calibra solo con movimiento:
    - Giroscopio: dejarlo quieto unos segundos.
    - Acelerómetro: orientarlo en distintas posiciones (ejes X/Y/Z arriba/abajo) y mantener cada una un momento.
    - Magnetómetro: moverlo describiendo figuras en 8 en el aire.
    - Sistema: sube a 3 cuando los tres anteriores están calibrados.
  - **Euler[heading,roll,pitch]**: orientación en grados.
  - **LinAccel[x,y,z]**: aceleración lineal en m/s² (gravedad ya restada).
  - **Temp**: temperatura del chip en °C (sirve como indicador rápido de que el sensor responde, no es una medición de precisión).

## 4. Siguiente paso

Con `sys=3` estable, mover el sensor a mano replicando aproximadamente los ejes de interés (flexo-extensión) y verificar que el ángulo reportado tiene sentido físico y no hay saltos/ruido excesivo. Si el comportamiento es consistente, este mismo patrón de lectura (`getEvent` + `getCalibration`) es la base para el firmware de adquisición sincronizada mencionado en el README.

## 5. Sobremuestreo (oversampling) — `test_bno055_oversampling/test_bno055_oversampling.ino`

**Nota:** este sketch vive en su propia carpeta `Firmware/test_bno055_oversampling/` (no dentro de `test_bno055/`) porque Arduino IDE compila juntos todos los `.ino` de una misma carpeta como un solo sketch -- tenerlos separados evita choques de `bno`, `setup()`, `loop()` duplicados.

Este segundo sketch promedia N lecturas crudas del BNO055 antes de reportar cada dato, para reducir el ruido aleatorio de la señal sin agregar hardware (mismo principio estadístico que promediar varios IMUs físicos, pero solo ataca ruido aleatorio — no corrige bias/drift sistemático, para eso hace falta calibración).

- Los ángulos se promedian como vector (seno/coseno) y no como número directo, porque el heading da la vuelta en 0/360 y un promedio ingenuo daría resultados incorrectos cerca de ese punto.
- Configurable en el código: `N_SAMPLES` (muestras por bloque) y `SAMPLE_INTERVAL_MS` (separación entre muestras crudas). La tasa de salida resultante es `1000 / (N_SAMPLES * SAMPLE_INTERVAL_MS)` Hz — con los valores por defecto (10 y 10 ms) da 10 Hz. Si necesitas mantener el ≥100 Hz de salida del requerimiento técnico del README, baja `N_SAMPLES`.
- Salida por Serial en formato CSV: `raw_heading,raw_roll,raw_pitch,avg_heading,avg_roll,avg_pitch,n,sys,gyro,accel,mag` (raw = primera muestra cruda del bloque, avg = promedio del bloque), lista para pegar en un `.csv` y analizar.

**Cómo comprobar que realmente reduce el ruido:** con el sensor quieto sobre una superficie estable, registra ~30 s con `test_bno055.ino` (dato crudo) y ~30 s con este sketch (dato promediado), calcula la desviación estándar de cada columna en Excel/Python, y compara — la del promedio debería salir menor, idealmente cerca de `std_crudo / sqrt(N_SAMPLES)`.

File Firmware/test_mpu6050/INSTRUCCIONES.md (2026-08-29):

# Test IMU MPU6050 (ESP32)

Sketch de prueba para el MPU6050/GY-521 que ya tienen en inventario (ver `Reportes-Semanales/S3/Resumen-Semana3.md`, tabla de IMU). A diferencia del BNO055, este sketch SÍ programa el filtro de fusión (complementario) por software, porque el MPU6050 no lo trae integrado.

## 1. Conexionado

| MPU6050 / GY-521 | ESP32 |
|---|---|
| VCC | 3V3 (la mayoría de módulos GY-521 traen regulador a bordo, revisa el tuyo si acepta 3.3V directo) |
| GND | GND |
| SDA | GPIO21 |
| SCL | GPIO22 |
| AD0 | GND (dirección 0x68, la que usa el sketch) o 3V3 (0x69) |
| INT | sin conectar (no se usa) |

## 2. Software (Arduino IDE)

1. Administrador de bibliotecas → instalar **Adafruit MPU6050**, **Adafruit Unified Sensor** y **Adafruit BusIO** (dependencias entre sí).
2. Abrir `test_mpu6050.ino` como sketch independiente (está en su propia carpeta, igual que hicimos con `test_bno055_oversampling`).
3. Cargar y abrir el Monitor Serie a **115200 baudios**.

## 3. Qué esperar

- Al iniciar, el sketch pide mantener el sensor quieto ~2 segundos mientras calibra el offset del giroscopio (bias) — esto es necesario porque, a diferencia del BNO055, el MPU6050 no se autocalibra.
- Salida CSV: `raw_ax,raw_ay,raw_az,raw_gx,raw_gy,raw_gz,roll,pitch,yaw_solo_giro,temp_C`
  - `raw_a*`: aceleración cruda en m/s² (con gravedad incluida, no es aceleración lineal).
  - `raw_g*`: velocidad angular en rad/s, ya con el offset de calibración restado.
  - `roll,pitch`: ángulos del **filtro complementario** (acelerómetro + giroscopio) — esto reemplaza la fusión que el BNO055 hacía solo.
  - `yaw_solo_giro`: **a propósito sin corregir** — es la integración pura del giro en Z. Sirve para que veas en vivo el drift del que hablamos: con el sensor quieto, este valor se va a ir alejando de 0 poco a poco. No lo uses como dato válido, es solo demostrativo.
  - `temp_C`: temperatura del chip.

## 4. Limitaciones frente al BNO055 (recordatorio)

- **Sin magnetómetro**: no hay forma de obtener un heading/yaw absoluto — por eso `yaw_solo_giro` deriva sin límite.
- **Sin fusión integrada**: el roll/pitch que ves aquí depende del filtro complementario que programamos, no de un chip dedicado como en el BNO055.
- El peso del filtro (`GYRO_WEIGHT`, por defecto 0.98) controla el balance entre respuesta rápida (más giro) y estabilidad (más acelerómetro) — pueden ajustarlo si ven roll/pitch muy ruidoso o muy lento para seguir el movimiento real.

## 5. Siguiente paso

Como el MPU6050 tiene rol de validación cruzada (no medición primaria — ese es el AS5600), lo más útil es comparar su `roll`/`pitch` contra el ángulo del AS5600 en el mismo movimiento, y ver si detecta holgura/desalineamiento del pivote como se planteó en la arquitectura de sensores de la S2.

## 6. Visor en tiempo real (Python)

Igual que con el BNO055, hay un visor gráfico en `visor_python/visor_mpu6050.py` que lee el puerto serial y grafica roll/pitch/yaw en vivo, más los datos crudos de acelerómetro y giroscopio.

```
cd visor_python
pip install -r requirements.txt
python visor_mpu6050.py --port COM5
```

Detalles a tener en cuenta:

- El panel superior muestra `roll`/`pitch` (ya filtrados) y, en rojo punteado, `yaw (solo giro, DERIVA)` — está ahí a propósito para que veas el drift en vivo: con el sensor quieto, esa línea se va a ir alejando de 0 con el tiempo, mientras roll/pitch se mantienen estables gracias a la corrección del acelerómetro.
- El botón "Zero / Reset (solo vista)" solo aplica un offset visual en el gráfico — **no reinicia el drift real** que sigue acumulándose dentro del ESP32 (a diferencia del visor del BNO055, aquí es importante dejarlo claro porque el yaw sin corregir seguiría creciendo aunque resetees la vista).
- Si quieres comparar directamente contra el visor del BNO055 (`Firmware/test_bno055/visor_python/visor_imu.py`), puedes correr ambos sketches en dos ESP32/puertos distintos y abrir las dos ventanas en paralelo.

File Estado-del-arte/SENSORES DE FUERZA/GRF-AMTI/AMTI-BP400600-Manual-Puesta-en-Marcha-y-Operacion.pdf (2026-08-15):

### PONTIFICIA UNIVERSIDAD CATÓLICA DEL PERÚ

### FACULTAD DE CIENCIAS E INGENIERÍA

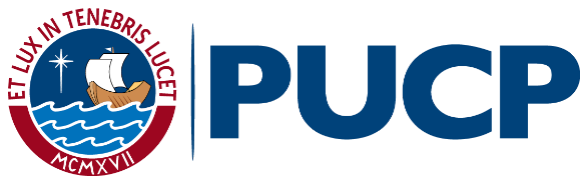
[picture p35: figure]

## LABORATORIO DE INVESTIGACIÓN EN BIOMECÁNICA Y ROBÓTICA APLICADA (LIBRA)

## MANUAL DE PUESTA EN MARCHA Y OPERACIÓN DE LAS PLATAFORMAS DE FUERZA MODULAR - AMTI

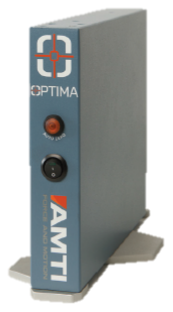
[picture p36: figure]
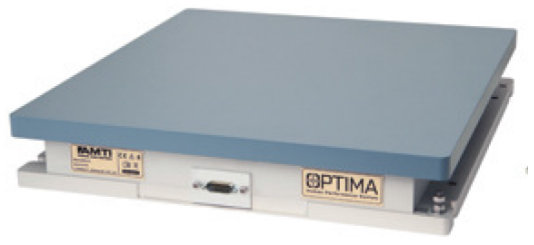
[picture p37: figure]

Información del documento

Nombre del documento: | Manual de puesta en marcha y operación de las plataformas de fuerza modular
Versión del documento: | 1.0
Fecha | 13-07-2016
Elaborado por | Yalhy del Rosario Melgarejo Chicchon

Revisado por

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
1. C

alib

r

a

ció

n
4
2. C

a

p

t

u

r

a

d

e la

d

a

t

a
6
3. A

n

álisis

d

e la

d

a

t

a
8

# Procedimiento de puesta en marcha y operación Plataforma de Fuerza Modular - AMTI BP400600

### 1. Calibración

- Primero se abrirá el software GEN5 y aparecerá la siguiente ventana (Ver Figura 1) donde se dará click en el botón “Find Amplifers” para que el programa detecte las plataformas que se encuentran conectadas a la computadora a través del amplificador.

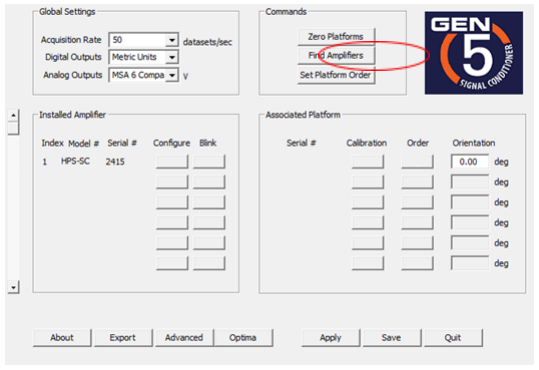
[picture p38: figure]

Figura 1 Interfaz del software GEN5 con Logo GEN5

Si todo se encuentra bien conectado aparecerán las plataformas conectadas en “Associated Platforms” y el logo de OPTIMA en vez del de GEN5 (Ver Figura 2) en la parte superior derecha.

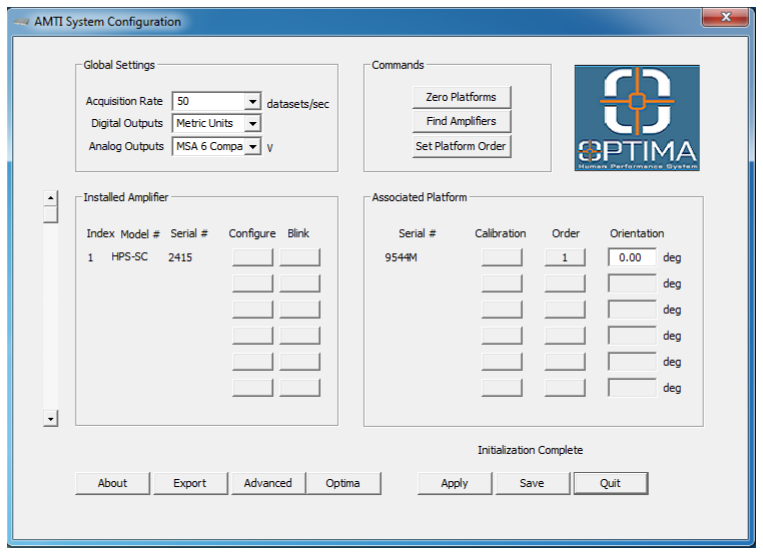
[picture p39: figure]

Figura 2 Interfaz del software GEN5 con Logo OPTIMA

- Para ver si la las plataformas se encuentran bien calibradas, se dará click en el botón (Ver Figura 3) que está al lado del número de serie de la plataforma conectada.

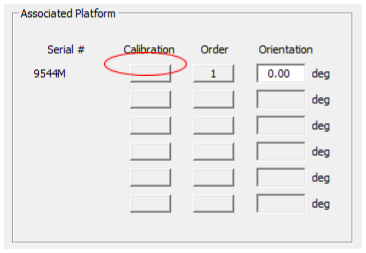
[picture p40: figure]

Figura 3 Associated Platform - Interfaz del software GEN5

Aparecerá una ventana (Ver Figura 4) con información de la plataforma como la calibración, modelo, serial #, largo, ancho, capacidad y resistencia. Además, mostrará el estado de la plataforma, si todo se encuentra en buen estado dirá que está lista para su uso. Finalmente, se dará click en “OK” para cerrar la ventana.

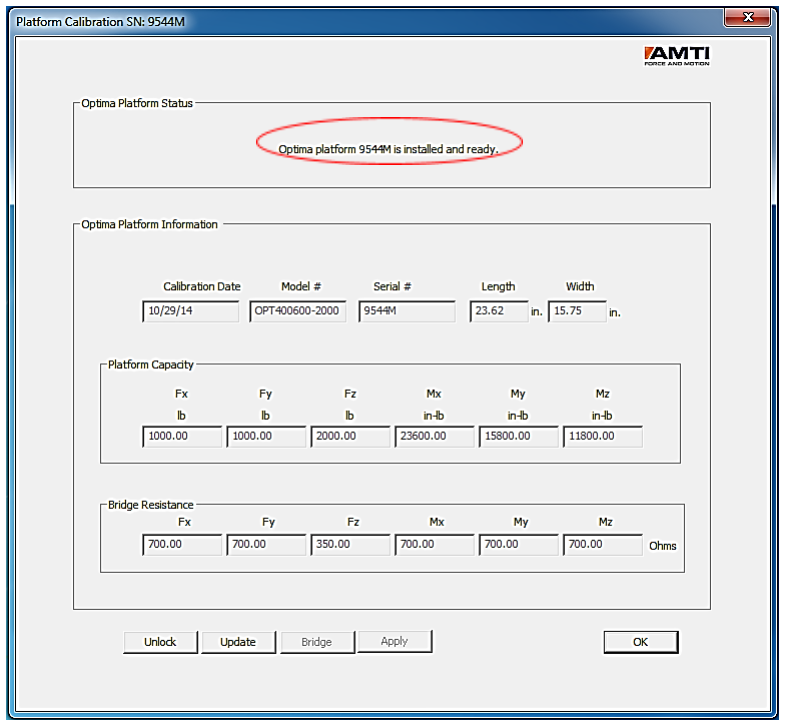
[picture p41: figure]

Figura 4 Opción Platform Calibration del software GEN5

### 2. Captura de la data

- Luego, se procederá a abrir el software AMTI- NetForce y se verá la siguiente ventana (Ver Figura 5). Para la toma de datos, se necesita tener el tiempo y la tasa de muestreo que se captarán de la muestra. Si se quiere cambiar estos dos parámetros en la ventana inicial del software AMTI- NetForce, se hará click en “Select/View Protocol” en la pestaña “Protocol”.

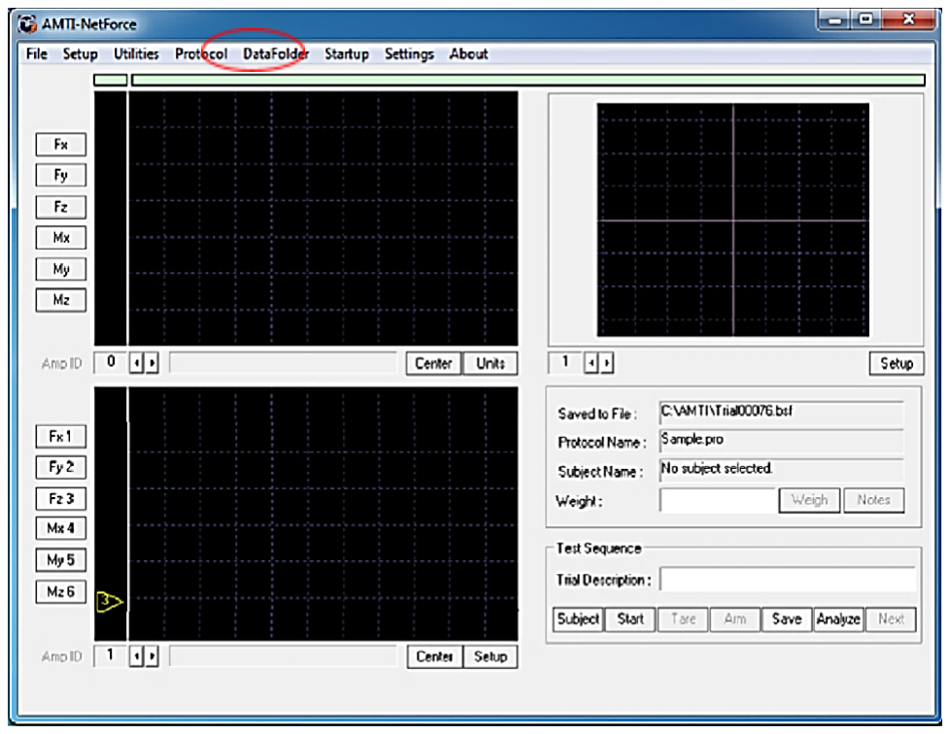
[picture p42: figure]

Figura 5 Interfaz del software AMTI-Netforce

Aparecerá la siguiente ventana (Ver Figura 6) donde se podrá colocar el tiempo en el cuadro de texto de “Duration”.

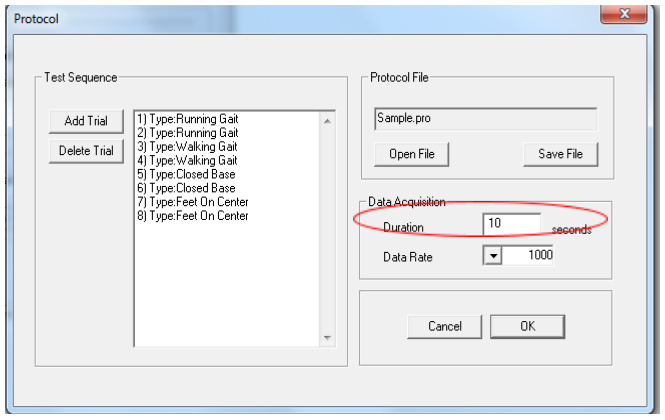
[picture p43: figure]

Figura 6 Opción Protocolo del software AMTI-NetForce

Y para cambiar la tasa de muestreo, se dará click en el botón y se elegirá la cantidad (Ver Figura 7) en la que se desea realizar la prueba.

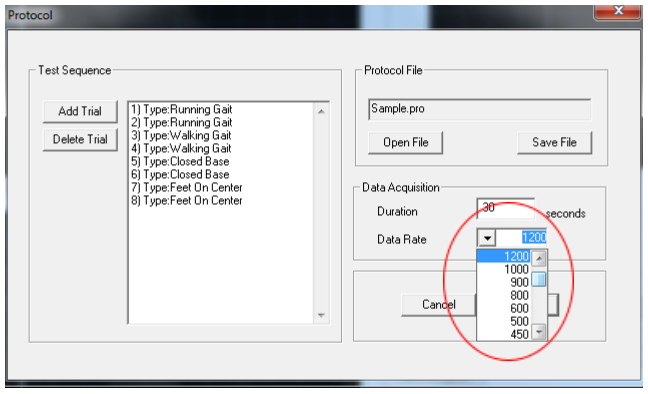
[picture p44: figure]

Figura 7 Opción Protocolo del software AMTI-Netforce

Al dar click en ok volverá a la ventana anterior (Ver Figura 8) donde para iniciar la prueba dará click en Start. Si desea detener la toma pondrá Stop y si desea guardarla, Save.

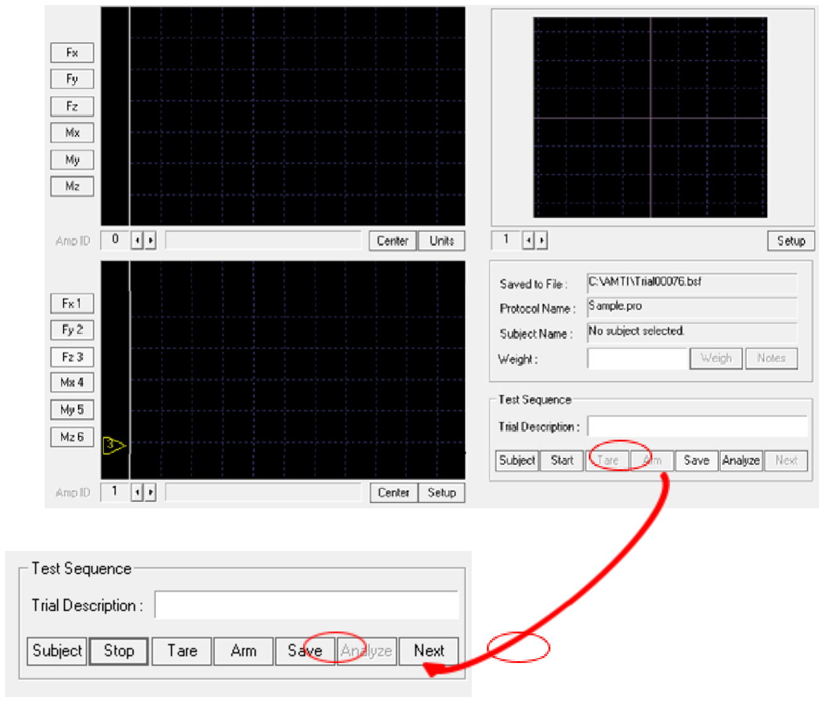
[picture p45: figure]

Figura 8 Pasos para toma de prueba con el software AMTI-Netforce

### 3. Análisis de la data

- Para poder analizar la data guardada anteriormente, se procederá abrir el software BioAnalysis y para esto se necesita colocar la llave Sentinel, ya que sin esta no se podrá hacer uso del software. Al abrirse la ventana (Ver Figura 9), se escogerá el tipo de análisis que se quiere hacer: marcha, balance o fuerza (de lo que dependerá las gráficas que se podrán ver). Para este caso se mostrará un ejemplo de marcha, por lo que se busca la opción “Gait” en la opción “Analysis”.

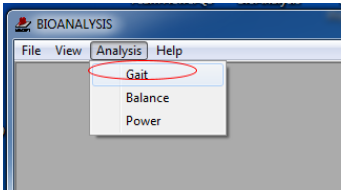
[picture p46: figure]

Figura 9 Pestaña Analysis del software BioAnalysis

Se abrirá una ventana (Ver Figura 10) y se buscará el archivo o los archivos guardados con el software AMTI- NetForce, se seleccionarán y se dará “OK” para poder visualizar cada data guardada.

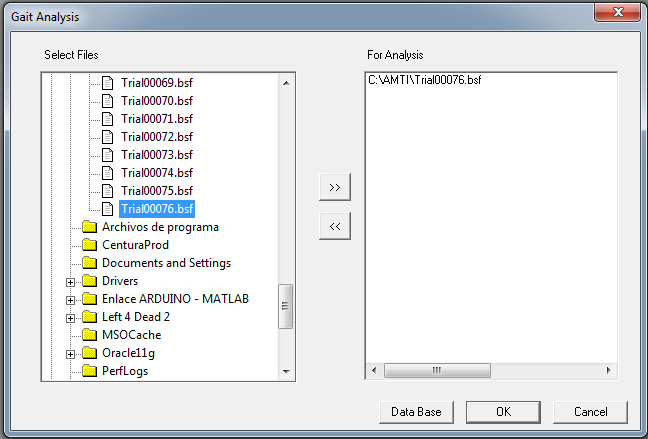
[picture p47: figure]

Figura 10 Elección de prueba en Gait Analysis del software BioAnalysis

Se mostrará la siguiente ventana (Ver Figura 11) con la gráfica de los datos obtenidos.

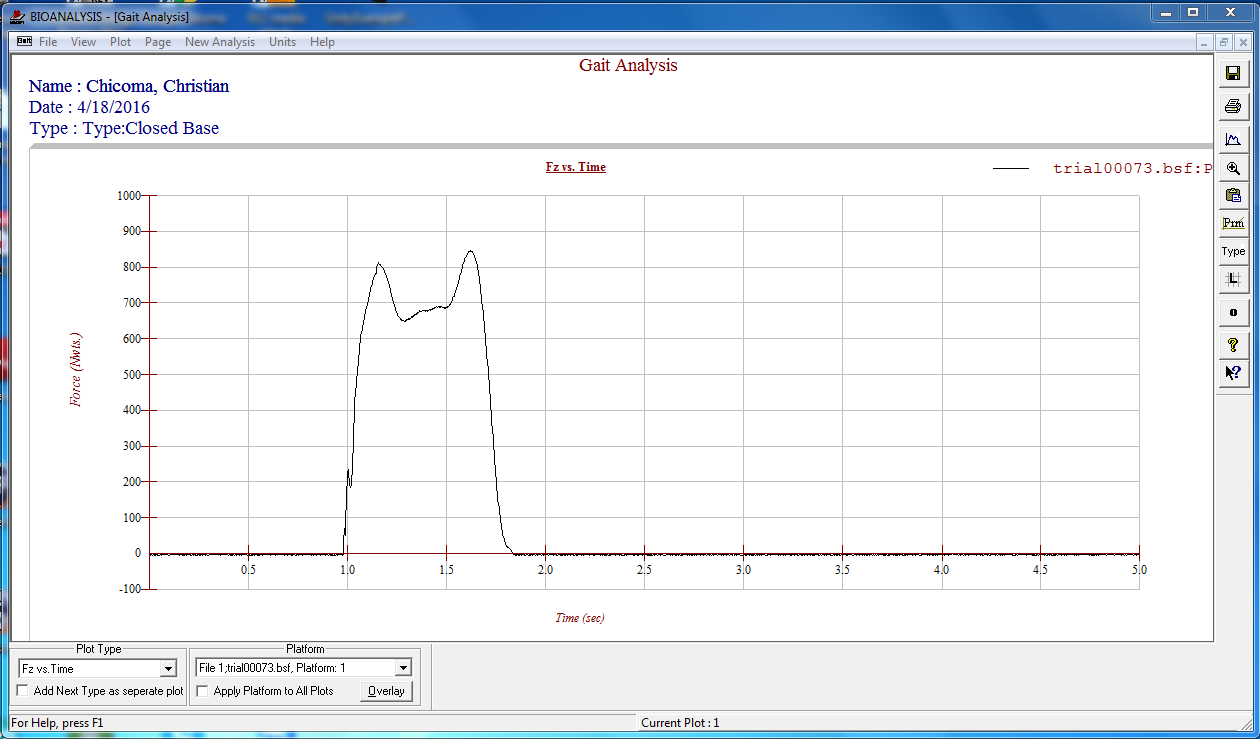
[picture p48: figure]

Figura 11 Gait Analysis del software BioAnalysis

Para ver las diferentes gráficas que se obtiene con una prueba puede cambiar en la opción de Plot Type (Ver Figura 12) el tipo de gráficas que desea analizar, entre las cuales se tiene Fz vs Time, Fy vs Time, Fx vs Time, Mz vs Time, My vs Time, Mx vs Time, centro de presión, torque vertical y Fz normalizada.

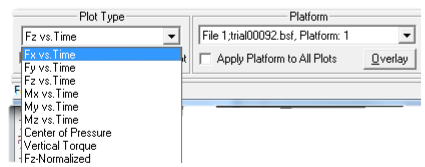
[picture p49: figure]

Figura 12 Opciones de Plot Type

Y para ver los valores obtenidos en ambas plataformas, se cambiará de opción en Platform (Ver Figura 13) como se muestra en la figura.

Figura 13 Opciones de Platform

Para poder ver la data cruda entregada por las plataformas, se hace click en “Data” de la pestaña “View” (Ver Figura 9) y se mostrará la siguiente ventana (Ver Figura 14) donde se muestra los datos que ha sido capturado en el tiempo seleccionado.

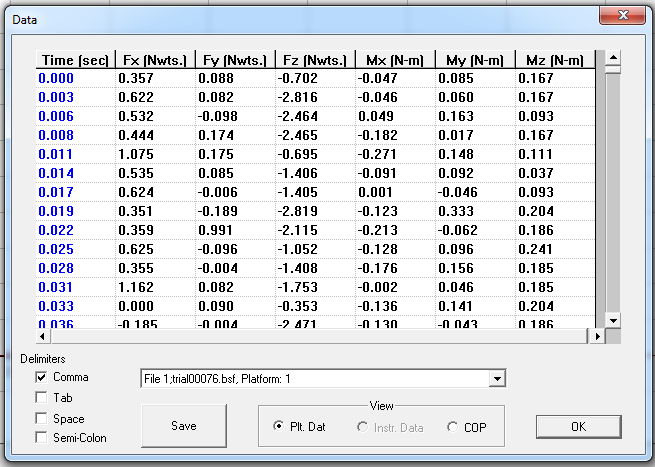
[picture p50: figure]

Figura 14 Opción Data de Gait Analysis

En esta se ventana solo se muestran los valores de las fuerzas y momentos en cada eje respectivamente en todo momento de la prueba. Para ver los datos del centro de presión (COP) de toda la prueba (Ver Figura 15), elegir la opción COP en la sección View de la ventana anterior.

Figura 15 View - Interfaz Data de Gait Analysis

Se podrá observar la siguiente ventana.

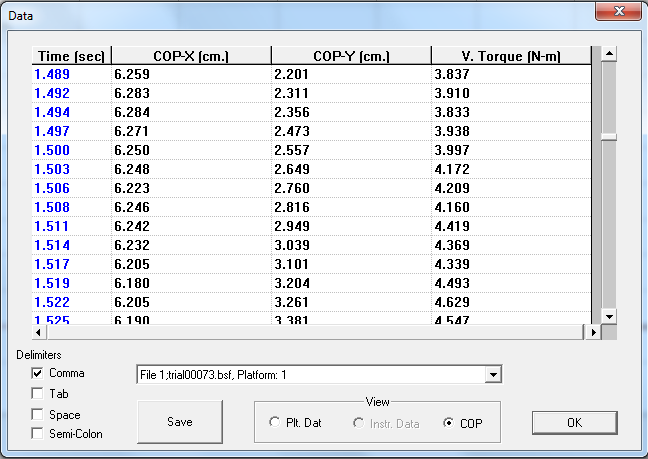
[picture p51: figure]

Figura 16 Opción COP de Gait Analysis

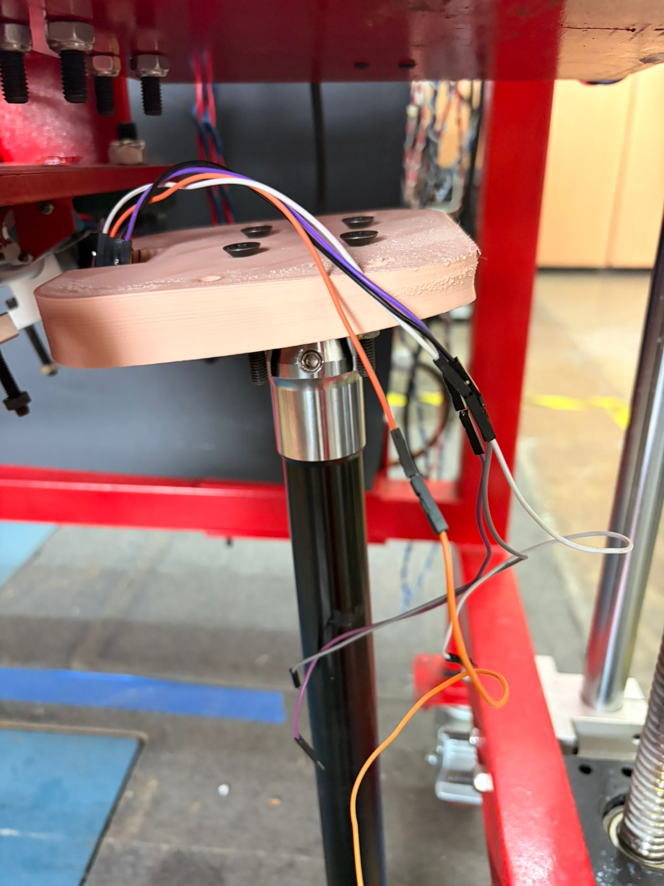
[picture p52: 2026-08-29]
Evidencias/pruebas-imu-S4/imu-montaje-pylon-plataforma.png

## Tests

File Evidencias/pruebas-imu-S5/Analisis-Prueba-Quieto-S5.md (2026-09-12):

# Análisis — prueba "sensor quieto" BNO055 (10/09/2026)

Dos grabaciones hechas con `log_csv_bno055.py` (COM7, `test_wifi_ap_bno055.ino`), sensor inmóvil en una posición que visualmente se ve como 0°. Datos crudos en esta misma carpeta: `bno055_20260910_161442.csv` y `bno055_20260910_162052.csv`.

## Prueba 1 (16:14:42, ~28.7 s, 251 filas)

| variable | promedio | desv. estándar | mín | máx |
|---|---|---|---|---|
| heading | 338.46° | 82.41°* | 0.00° | 359.94° |
| roll | -1.36° | 0.31° | -2.19° | 0.06° |
| pitch | 1.59° | 1.84° | -2.00° | 6.00° |
| ax | -0.09 | 0.05 | -0.32 | 0.08 |
| ay | -0.02 | 0.31 | -0.66 | 0.75 |
| az | -0.24 | 0.01 | -0.28 | -0.20 |

*El std de heading no es real: la lectura cruza el límite 0°/360° (llega a 359.94° y también a 0.00°), y el promedio/desviación estándar calculados de forma lineal sobre un ángulo circular no tienen sentido en ese caso. Para heading hace falta estadística circular (o "desenrollar" el ángulo) antes de sacar conclusiones.

**Calibración durante toda la prueba: `sys=0, gyro=0, accel=0, mag=0`.** El BNO055 nunca reportó estar calibrado — ni siquiera el giroscopio, que normalmente sube a 3/3 en pocos segundos con el sensor quieto. Esto es sospechoso por dos motivos: o el sensor de verdad no está calibrado (lo cual invalida cualquier conclusión de ruido, porque un heading/pitch sin calibrar es normal que se vea inestable), o `getCalStatus()` no está leyendo bien el registro. Antes de sacar conclusiones de ruido hay que resolver esto — ver pendientes abajo.

## Prueba 2 (16:20:52, ~30.0 s, 287 filas)

**Las 287 filas salieron en exactamente `0.000` en las 10 columnas (heading, roll, pitch, ax, ay, az), sin ninguna variación.** Esto no es un sensor "muy estable" — es físicamente imposible que un IMU real dé el mismo valor exacto miles de veces seguidas, especialmente en heading (que depende del magnetómetro). Lo más probable es que el sensor dejó de mandar datos en vivo justo después de que el script mandara el comando de borrar cero ('c') al iniciar, y lo que se grabó fue un valor congelado o un error silencioso de lectura I2C. **Este archivo no sirve para análisis de ruido** — hay que repetir la prueba mirando el Monitor Serie en vivo (no solo el CSV al final) para confirmar si el ESP32 se quedó pegado o si de verdad hay un bug en el manejo del comando 'c'.

## Filtro: EMA (promedio móvil exponencial) vs. Machine Learning

Decisión: empezar con un filtro simple, no con ML.

Razón: el ruido que se ve en la Prueba 1 (pitch con std ~1.8°) tiene toda la pinta de ruido instrumental normal (gaussiano, sin patrón), no un problema de reconocer una forma compleja en los datos — para eso un filtro clásico es exactamente la herramienta correcta, es barato de correr en el ESP32, no necesita datos de entrenamiento, y es fácil de explicar/justificar en el informe. El BNO055 además ya corre internamente una fusión sensorial tipo Kalman (modo NDOF, combina acelerómetro + giroscopio + magnetómetro) — meter otra capa de ML encima sería resolver con una herramienta pesada un problema que ya está parcialmente resuelto por el propio sensor. ML tendría sentido si el "ruido" tuviera un patrón dependiente del contexto (por ejemplo, error que cambia según la temperatura o la posición), que no es lo que se ve aquí.

Filtro propuesto: **promedio móvil exponencial (EMA)**:

```
filtrado[i] = alpha * crudo[i] + (1 - alpha) * filtrado[i-1]
```

`alpha` más chico = más suavizado pero más lento en reaccionar a un cambio real de orientación (más "delay"). Como el proyecto no exige baja latencia de lazo cerrado (ver README), se puede usar un alpha bajo sin problema.

Prueba con los datos reales de pitch (Prueba 1):

| filtro | desv. estándar |
|---|---|
| crudo | 1.840° |
| EMA alpha=0.15 | 1.545° |
| EMA alpha=0.05 | 1.164° |

Ver `filtro-ema-comparacion-pitch-S5.png` — el filtro reduce el ruido, pero **no es un sustituto de resolver el problema de calibración de arriba**: si el sensor no está bien calibrado, el filtro solo suaviza una señal que de por sí está sesgada, no corrige el sesgo.

## Pendientes que salen de este análisis

1. Confirmar por qué la calibración se queda en 0,0,0,0 durante toda la prueba (¿`getCalStatus()` mal leído, o el sensor de verdad sin calibrar?). Probar la rutina de calibración del BNO055 (mover en figura de 8 para el magnetómetro, rotar por varias orientaciones para el acelerómetro, dejar quieto unos segundos para el giroscopio) y repetir la prueba.
2. Repetir la Prueba 2 mirando el Monitor Serie en vivo — confirmar si el "todo en cero" es un cuelgue del ESP32, un bug del comando 'c', o un error de lectura I2C puntual.
3. Para heading, usar una métrica circular (o desenrollar el ángulo) en vez de std lineal si se necesita cuantificar su ruido.
4. Si después de calibrar bien el ruido sigue siendo un problema, implementar el EMA directamente en el firmware (una línea por eje, muy barato) en vez de solo en post-proceso Python.

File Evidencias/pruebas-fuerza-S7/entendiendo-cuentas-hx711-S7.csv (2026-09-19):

paso | evento | raw_code | tara_guardada | delta_counts | factor_N_por_cuenta | force_N | explicacion
1 | celda vacia, sin tarar (calibrated=0) | -22861 | - | - | - | 0.0 | raw_code crudo, no significa nada en Newtons todavia
1 | celda vacia, sin tarar (calibrated=0) | -22877 | - | - | - | 0.0 | raw_code crudo, no significa nada en Newtons todavia
1 | celda vacia, sin tarar (calibrated=0) | -22870 | - | - | - | 0.0 | raw_code crudo, no significa nada en Newtons todavia
1 | celda vacia, sin tarar (calibrated=0) | -22758 | - | - | - | 0.0 | raw_code crudo, no significa nada en Newtons todavia
1 | celda vacia, sin tarar (calibrated=0) | -22847 | - | - | - | 0.0 | raw_code crudo, no significa nada en Newtons todavia
1 | celda vacia, sin tarar (calibrated=0) | -22976 | - | - | - | 0.0 | raw_code crudo, no significa nada en Newtons todavia
2 | escribis 't' -> el sketch promedia esas 6 lecturas | - | -22864.8 | - | - | - | tara_guardada = promedio de las lecturas de arriba, queda guardado en flash
3 | pusiste una masa patron de 2.000 kg (todavia sin 'k') | -4980 | -22864.8 | 17884.8 | - | - | raw_code ya cambio por la masa, pero aun no hay factor calculado
3 | pusiste una masa patron de 2.000 kg (todavia sin 'k') | -5010 | -22864.8 | 17854.8 | - | - | raw_code ya cambio por la masa, pero aun no hay factor calculado
3 | pusiste una masa patron de 2.000 kg (todavia sin 'k') | -5005 | -22864.8 | 17859.8 | - | - | raw_code ya cambio por la masa, pero aun no hay factor calculado
3 | pusiste una masa patron de 2.000 kg (todavia sin 'k') | -4995 | -22864.8 | 17869.8 | - | - | raw_code ya cambio por la masa, pero aun no hay factor calculado
3 | pusiste una masa patron de 2.000 kg (todavia sin 'k') | -5020 | -22864.8 | 17844.8 | - | - | raw_code ya cambio por la masa, pero aun no hay factor calculado
3 | pusiste una masa patron de 2.000 kg (todavia sin 'k') | -5001 | -22864.8 | 17863.8 | - | - | raw_code ya cambio por la masa, pero aun no hay factor calculado
4 | escribis 'k2.0' -> el sketch calcula el factor | -5001.8 | -22864.8 | 17863.0 | 0.00109798 | 19.6133 | factor = (masa_kg * 9.80665) / delta_counts = fuerza_conocida / delta_counts; se guarda en flash
5 | celda vacia de nuevo (deberia dar ~0 N) | -22850 | -22864.8 | 14.8 | 0.00109798 | 0.0163 | force_N = (raw_code - tara) * factor -- equivale a ~0.002 kg
5 | misma masa patron de 2 kg otra vez (deberia dar ~19.6 N) | -5005 | -22864.8 | 17859.8 | 0.00109798 | 19.6098 | force_N = (raw_code - tara) * factor -- equivale a ~2.000 kg
5 | una masa DISTINTA que nunca calibraste directo | -13900 | -22864.8 | 8964.8 | 0.00109798 | 9.8432 | force_N = (raw_code - tara) * factor -- equivale a ~1.004 kg

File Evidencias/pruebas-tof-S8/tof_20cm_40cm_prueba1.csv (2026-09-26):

t_s | dist1_mm | status1 | dist2_mm | status2
0.001 | 436 | 0 | 227 | 0
0.001 | 439 | 0 | 216 | 0
0.001 | 436 | 0 | 227 | 0
0.001 | 439 | 0 | 216 | 0
0.002 | 436 | 0 | 227 | 0
0.002 | 439 | 0 | 216 | 0
0.002 | 436 | 0 | 227 | 0
0.002 | 439 | 0 | 216 | 0
0.002 | 436 | 0 | 227 | 0
0.002 | 439 | 0 | 216 | 0
0.003 | 436 | 0 | 227 | 0
0.003 | 439 | 0 | 216 | 0
0.003 | 436 | 0 | 227 | 0
0.003 | 439 | 0 | 216 | 0
0.003 | 436 | 0 | 227 | 0
0.003 | 439 | 0 | 216 | 0
0.004 | 436 | 0 | 227 | 0
0.004 | 439 | 0 | 216 | 0
0.004 | 436 | 0 | 227 | 0
0.004 | 439 | 0 | 216 | 0
0.004 | 436 | 0 | 227 | 0
0.005 | 439 | 0 | 216 | 0
0.005 | 436 | 0 | 227 | 0
0.005 | 439 | 0 | 216 | 0
0.005 | 436 | 0 | 227 | 0
0.005 | 439 | 0 | 216 | 0
0.005 | 436 | 0 | 227 | 0
0.006 | 439 | 0 | 216 | 0
0.006 | 436 | 0 | 227 | 0
0.006 | 439 | 0 | 216 | 0
0.006 | 436 | 0 | 227 | 0
0.006 | 439 | 0 | 216 | 0
0.006 | 436 | 0 | 227 | 0
0.007 | 439 | 0 | 216 | 0
0.007 | 436 | 0 | 227 | 0
0.007 | 439 | 0 | 216 | 0
0.007 | 436 | 0 | 227 | 0
0.007 | 439 | 0 | 216 | 0
0.007 | 436 | 0 | 227 | 0
0.008 | 439 | 0 | 216 | 0
0.008 | 436 | 0 | 227 | 0
0.008 | 439 | 0 | 216 | 0
0.008 | 436 | 0 | 227 | 0
0.008 | 439 | 0 | 216 | 0
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

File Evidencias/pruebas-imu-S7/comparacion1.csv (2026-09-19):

heading_crudo | roll_crudo | pitch_crudo | heading_filtrado | roll_filtrado | pitch_filtrado
0.00 | 0.00 | 0.00 | 0.00 | 0.00 | 0.00
205.06 | -1.00 | 175.38 | 344.51 | -0.10 | 17.54
205.06 | -1.00 | 175.38 | 330.56 | -0.19 | 33.32
205.06 | -1.00 | 175.38 | 318.01 | -0.27 | 47.53
205.06 | -1.00 | 175.38 | 306.72 | -0.34 | 60.31
205.06 | -1.00 | 175.38 | 296.55 | -0.41 | 71.82
205.06 | -1.00 | 175.38 | 287.40 | -0.47 | 82.17
205.06 | -1.00 | 175.38 | 279.17 | -0.52 | 91.49
205.06 | -1.00 | 175.38 | 271.76 | -0.57 | 99.88
205.06 | -1.00 | 175.38 | 265.09 | -0.61 | 107.43
205.06 | -1.00 | 175.38 | 259.09 | -0.65 | 114.23
205.06 | -1.00 | 175.38 | 253.68 | -0.69 | 120.34
205.06 | -1.00 | 175.38 | 248.82 | -0.72 | 125.84
205.06 | -1.00 | 175.38 | 244.45 | -0.75 | 130.80
205.06 | -1.00 | 175.38 | 240.51 | -0.77 | 135.25
205.06 | -1.00 | 175.38 | 236.96 | -0.79 | 139.27
205.06 | -1.00 | 175.38 | 233.77 | -0.81 | 142.88
205.06 | -1.00 | 175.38 | 230.90 | -0.83 | 146.13
205.06 | -1.00 | 175.38 | 228.32 | -0.85 | 149.05
205.06 | -1.00 | 175.38 | 225.99 | -0.86 | 151.68
205.06 | -1.00 | 175.38 | 223.90 | -0.88 | 154.05
205.06 | -1.00 | 175.38 | 222.02 | -0.89 | 156.19
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

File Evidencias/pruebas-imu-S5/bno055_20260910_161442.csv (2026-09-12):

t_s | calib_sys | calib_gyro | calib_accel | calib_mag | heading | roll | pitch | ax | ay | az
1.346 | 0 | 0 | 0 | 0 | 0.06 | 0.06 | 0.0 | -0.32 | -0.24 | -0.25
1.460 | 0 | 0 | 0 | 0 | 0.19 | -2.06 | 2.44 | 0.05 | 0.2 | -0.24
1.576 | 0 | 0 | 0 | 0 | 359.94 | -1.88 | 2.81 | 0.01 | 0.25 | -0.25
1.690 | 0 | 0 | 0 | 0 | 359.94 | -1.5 | 2.88 | -0.08 | 0.25 | -0.25
1.806 | 0 | 0 | 0 | 0 | 359.31 | -0.88 | 1.25 | -0.17 | -0.01 | -0.23
1.921 | 0 | 0 | 0 | 0 | 359.44 | -0.88 | 0.81 | -0.16 | -0.12 | -0.25
2.037 | 0 | 0 | 0 | 0 | 359.5 | -0.94 | 1.44 | -0.13 | 0.0 | -0.27
2.151 | 0 | 0 | 0 | 0 | 359.5 | -0.94 | 2.75 | -0.16 | 0.19 | -0.24
2.265 | 0 | 0 | 0 | 0 | 359.5 | -0.81 | 2.06 | -0.2 | 0.07 | -0.24
2.379 | 0 | 0 | 0 | 0 | 359.75 | -0.88 | 1.94 | -0.2 | 0.09 | -0.25
2.493 | 0 | 0 | 0 | 0 | 359.88 | -1.06 | 2.56 | -0.14 | 0.21 | -0.26
2.608 | 0 | 0 | 0 | 0 | 359.88 | -1.19 | 1.25 | -0.12 | -0.03 | -0.25
2.722 | 0 | 0 | 0 | 0 | 359.75 | -1.44 | 1.0 | -0.03 | -0.08 | -0.25
2.837 | 0 | 0 | 0 | 0 | 359.69 | -1.5 | 0.56 | -0.06 | -0.17 | -0.26
2.953 | 0 | 0 | 0 | 0 | 359.81 | -1.44 | 0.75 | -0.07 | -0.15 | -0.27
3.067 | 0 | 0 | 0 | 0 | 359.81 | -1.62 | 0.38 | -0.04 | -0.22 | -0.25
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

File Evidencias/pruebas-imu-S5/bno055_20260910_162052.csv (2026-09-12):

t_s | calib_sys | calib_gyro | calib_accel | calib_mag | heading | roll | pitch | ax | ay | az
0.050 | 0 | 0 | 0 | 0 | 0.0 | 0.0 | 0.0 | 0.0 | 0.0 | 0.0
0.155 | 0 | 0 | 0 | 0 | 0.0 | 0.0 | 0.0 | 0.0 | 0.0 | 0.0
0.260 | 0 | 0 | 0 | 0 | 0.0 | 0.0 | 0.0 | 0.0 | 0.0 | 0.0
0.365 | 0 | 0 | 0 | 0 | 0.0 | 0.0 | 0.0 | 0.0 | 0.0 | 0.0
0.470 | 0 | 0 | 0 | 0 | 0.0 | 0.0 | 0.0 | 0.0 | 0.0 | 0.0
0.575 | 0 | 0 | 0 | 0 | 0.0 | 0.0 | 0.0 | 0.0 | 0.0 | 0.0
0.680 | 0 | 0 | 0 | 0 | 0.0 | 0.0 | 0.0 | 0.0 | 0.0 | 0.0
0.785 | 0 | 0 | 0 | 0 | 0.0 | 0.0 | 0.0 | 0.0 | 0.0 | 0.0
0.890 | 0 | 0 | 0 | 0 | 0.0 | 0.0 | 0.0 | 0.0 | 0.0 | 0.0
0.996 | 0 | 0 | 0 | 0 | 0.0 | 0.0 | 0.0 | 0.0 | 0.0 | 0.0
1.100 | 0 | 0 | 0 | 0 | 0.0 | 0.0 | 0.0 | 0.0 | 0.0 | 0.0
1.205 | 0 | 0 | 0 | 0 | 0.0 | 0.0 | 0.0 | 0.0 | 0.0 | 0.0
1.310 | 0 | 0 | 0 | 0 | 0.0 | 0.0 | 0.0 | 0.0 | 0.0 | 0.0
1.415 | 0 | 0 | 0 | 0 | 0.0 | 0.0 | 0.0 | 0.0 | 0.0 | 0.0
1.520 | 0 | 0 | 0 | 0 | 0.0 | 0.0 | 0.0 | 0.0 | 0.0 | 0.0
1.625 | 0 | 0 | 0 | 0 | 0.0 | 0.0 | 0.0 | 0.0 | 0.0 | 0.0
1.730 | 0 | 0 | 0 | 0 | 0.0 | 0.0 | 0.0 | 0.0 | 0.0 | 0.0
1.835 | 0 | 0 | 0 | 0 | 0.0 | 0.0 | 0.0 | 0.0 | 0.0 | 0.0
1.940 | 0 | 0 | 0 | 0 | 0.0 | 0.0 | 0.0 | 0.0 | 0.0 | 0.0
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

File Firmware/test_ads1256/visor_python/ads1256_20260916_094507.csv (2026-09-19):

t_s | raw_code | voltage_V | force_N | tared | calibrated
0.001 | 0456 | 0.001259 | 0.0 | 0 | 0
0.001 | 0456 | 0.001259 | 0.0 | 0 | 0
0.002 | 0456 | 0.001259 | 0.0 | 0 | 0
0.002 | 0456 | 0.001259 | 0.0 | 0 | 0
0.002 | 0456 | 0.001259 | 0.0 | 0 | 0
0.003 | 0456 | 0.001259 | 0.0 | 0 | 0
0.003 | 0456 | 0.001259 | 0.0 | 0 | 0
0.004 | 0456 | 0.001259 | 0.0 | 0 | 0
0.004 | 0456 | 0.001259 | 0.0 | 0 | 0
0.004 | 0456 | 0.001259 | 0.0 | 0 | 0
0.005 | 0456 | 0.001259 | 0.0 | 0 | 0
0.005 | 0456 | 0.001259 | 0.0 | 0 | 0
0.005 | 0456 | 0.001259 | 0.0 | 0 | 0
0.005 | 0456 | 0.001259 | 0.0 | 0 | 0
0.006 | 0456 | 0.001259 | 0.0 | 0 | 0
0.006 | 0456 | 0.001259 | 0.0 | 0 | 0
0.006 | 0456 | 0.001259 | 0.0 | 0 | 0
0.007 | 0456 | 0.001259 | 0.0 | 0 | 0
0.007 | 0456 | 0.001259 | 0.0 | 0 | 0
0.007 | 0456 | 0.001259 | 0.0 | 0 | 0
0.008 | 0456 | 0.001259 | 0.0 | 0 | 0
0.008 | 0456 | 0.001259 | 0.0 | 0 | 0
0.009 | 0456 | 0.001259 | 0.0 | 0 | 0
0.009 | 0456 | 0.001259 | 0.0 | 0 | 0
0.009 | 0456 | 0.001259 | 0.0 | 0 | 0
0.010 | 0456 | 0.001259 | 0.0 | 0 | 0
0.010 | 0456 | 0.001259 | 0.0 | 0 | 0
0.010 | 0456 | 0.001259 | 0.0 | 0 | 0
0.011 | 0456 | 0.001259 | 0.0 | 0 | 0
0.011 | 0456 | 0.001259 | 0.0 | 0 | 0
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

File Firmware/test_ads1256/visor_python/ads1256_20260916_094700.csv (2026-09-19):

t_s | raw_code | voltage_V | force_N | tared | calibrated
0.003 | 273193 | 0.001272 | 0.0 | 0 | 0
0.004 | 1315512 | 0.006126 | 0.0 | 0 | 0
0.005 | 267028 | 0.001243 | 0.0 | 0 | 0
0.006 | 1644957 | 0.007660 | 0.0 | 0 | 0
0.007 | 264455 | 0.001231 | 0.0 | 0 | 0
0.007 | 248008 | 0.001155 | 0.0 | 0 | 0
0.008 | 197579 | 0.000920 | 0.0 | 0 | 0
0.009 | 249550 | 0.001162 | 0.0 | 0 | 0
0.009 | 197584 | 0.000920 | 0.0 | 0 | 0
0.010 | -1710333 | -0.007964 | 0.0 | 0 | 0
0.011 | 254433 | 0.001185 | 0.0 | 0 | 0
0.011 | -1842333 | -0.008579 | 0.0 | 0 | 0
0.012 | 255204 | 0.001188 | 0.0 | 0 | 0
0.013 | -460275 | -0.002143 | 0.0 | 0 | 0
0.013 | 260858 | 0.001215 | 0.0 | 0 | 0
0.014 | 526957 | 0.002454 | 0.0 | 0 | 0
0.014 | -1776427 | -0.008272 | 0.0 | 0 | 0
0.015 | 255718 | 0.001191 | 0.0 | 0 | 0
0.015 | -1579023 | -0.007353 | 0.0 | 0 | 0
0.016 | -1513240 | -0.007047 | 0.0 | 0 | 0
0.017 | -1447452 | -0.006740 | 0.0 | 0 | 0
0.017 | 4408265 | 0.020528 | 0.0 | 0 | 0
0.017 | 273450 | 0.001273 | 0.0 | 0 | 0
0.018 | 2566024 | 0.011949 | 0.0 | 0 | 0
0.018 | 272681 | 0.001270 | 0.0 | 0 | 0
0.019 | 1578770 | 0.007352 | 0.0 | 0 | 0
0.019 | 268055 | 0.001248 | 0.0 | 0 | 0
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

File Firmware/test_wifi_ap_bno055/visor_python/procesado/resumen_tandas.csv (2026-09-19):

tanda | rep | total | archivo | filas | heading_prom | heading_std | roll_prom | roll_std | pitch_prom | pitch_std | ax_prom | ax_std | ay_prom | ay_std | az_prom | az_std
bno055_quieto_reposo | 1 | 10 | bno055_quieto_reposo_rep1de10.csv | 257 | 205.0133 | 0.6904 | -0.2762 | 0.2909 | 175.0356 | 0.339 | -0.1122 | 0.0742 | -0.0356 | 0.067 | -0.1298 | 0.025
bno055_quieto_reposo | 2 | 10 | bno055_quieto_reposo_rep2de10.csv | 258 | 204.2251 | 0.2892 | -0.4699 | 0.4449 | 174.8503 | 0.551 | -0.0798 | 0.0869 | 0.0025 | 0.0952 | -0.1356 | 0.0187
bno055_quieto_reposo | 3 | 10 | bno055_quieto_reposo_rep3de10.csv | 259 | 205.2 | 0.8686 | -0.5082 | 0.1882 | 174.5448 | 0.387 | -0.0725 | 0.056 | 0.0425 | 0.0796 | -0.1382 | 0.0192
bno055_quieto_reposo | 4 | 10 | bno055_quieto_reposo_rep4de10.csv | 258 | 207.98 | 0.7727 | -0.551 | 0.312 | 174.9171 | 0.4126 | -0.0711 | 0.0708 | -0.0098 | 0.0768 | -0.1329 | 0.0169
bno055_quieto_reposo | 5 | 10 | bno055_quieto_reposo_rep5de10.csv | 258 | 207.8596 | 1.1553 | -0.8214 | 0.4397 | 174.7198 | 0.4455 | -0.02 | 0.0763 | 0.0218 | 0.0843 | -0.137 | 0.0173
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

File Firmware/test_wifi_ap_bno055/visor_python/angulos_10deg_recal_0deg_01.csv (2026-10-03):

t_s | calib_sys | calib_gyro | calib_accel | calib_mag | heading | roll | pitch
0.116 | 3 | 3 | 3 | 3 | 324.62 | -0.21 | -179.06
0.231 | 3 | 3 | 3 | 3 | 324.62 | -0.21 | -179.06
0.347 | 3 | 3 | 3 | 3 | 324.62 | -0.22 | -179.06
0.466 | 3 | 3 | 3 | 3 | 324.62 | -0.22 | -179.06
0.581 | 3 | 3 | 3 | 3 | 324.62 | -0.22 | -179.06
0.699 | 3 | 3 | 3 | 3 | 324.62 | -0.23 | -179.06
0.817 | 3 | 3 | 3 | 3 | 324.62 | -0.23 | -179.06
0.932 | 3 | 3 | 3 | 3 | 324.62 | -0.23 | -179.06
1.050 | 3 | 3 | 3 | 3 | 324.62 | -0.23 | -179.06
1.168 | 3 | 3 | 3 | 3 | 324.62 | -0.23 | -179.06
1.283 | 3 | 3 | 3 | 3 | 324.62 | -0.24 | -179.06
1.401 | 3 | 3 | 3 | 3 | 324.62 | -0.24 | -179.06
1.518 | 3 | 3 | 3 | 3 | 324.62 | -0.24 | -179.06
1.634 | 3 | 3 | 3 | 3 | 324.62 | -0.24 | -179.06
1.752 | 3 | 3 | 3 | 3 | 324.62 | -0.24 | -179.06
1.868 | 3 | 3 | 3 | 3 | 324.62 | -0.24 | -179.06
1.985 | 3 | 3 | 3 | 3 | 324.62 | -0.24 | -179.06
2.102 | 3 | 3 | 3 | 3 | 324.62 | -0.24 | -179.06
2.218 | 3 | 3 | 3 | 3 | 324.62 | -0.24 | -179.06
2.336 | 3 | 3 | 3 | 3 | 324.62 | -0.24 | -179.06
2.453 | 3 | 3 | 3 | 3 | 324.62 | -0.25 | -179.06
2.569 | 3 | 3 | 3 | 3 | 324.62 | -0.25 | -179.06
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

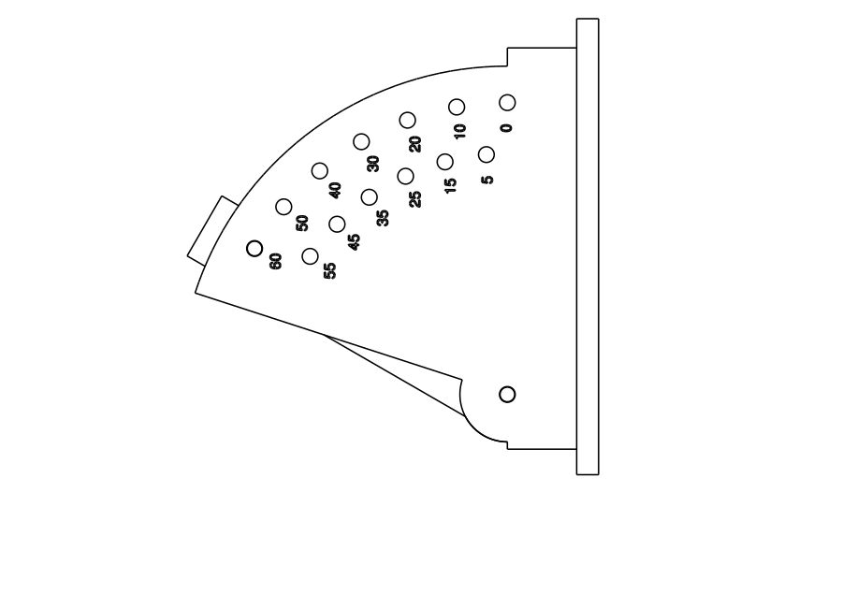
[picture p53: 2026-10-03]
Firmware/test_wifi_ap_bno055/soporte_angulos_imu/vista_lateral_60grados.png

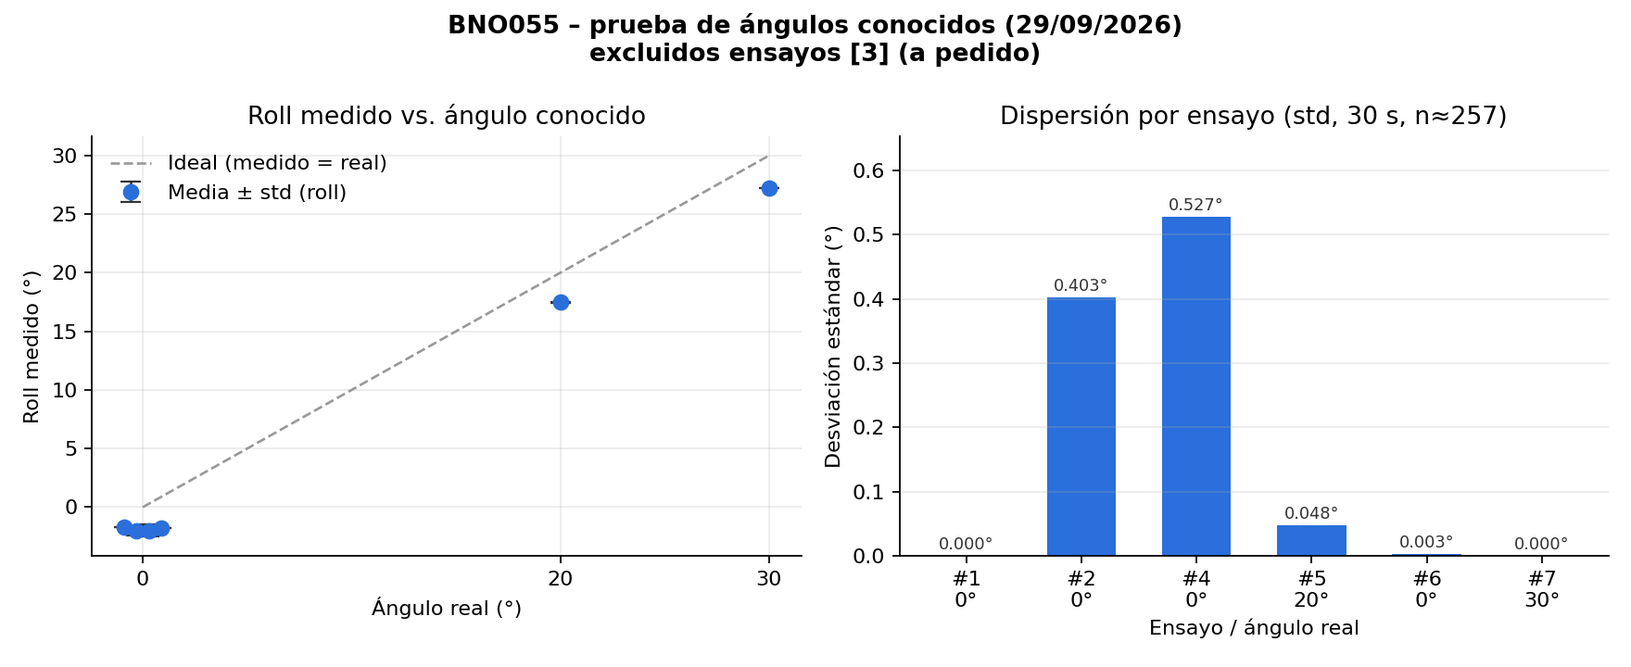
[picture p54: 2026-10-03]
Firmware/test_wifi_ap_bno055/visor_python/angulos_20260929_171116_std_roll_sin3.png

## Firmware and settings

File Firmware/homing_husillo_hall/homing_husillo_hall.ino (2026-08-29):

/*
 * Homing del eje del motor paso a paso (husillo) con iman + sensor Hall
 * Plataforma: ESP32 + driver de motor paso a paso (A4988/DRV8825/TMC2209,
 *             cualquiera con interfaz STEP/DIR estandar)
 *
 * IDEA: pegar un iman pequeño en un disco/colllarin que se monta en el eje
 * del motor, y fijar un sensor Hall en el chasis del motor -- una vez por
 * vuelta, el iman pasa frente al sensor y dispara una señal digital. Ese
 * es un punto FISICO, repetible y exacto del eje -- no depende de contar
 * pasos (que se puede perder si el motor patina/pierde pasos) ni de
 * gravedad/nivelacion (a diferencia del homing con acelerometro que ya
 * probamos para el pivote).
 *
 * PIEZA FISICA A IMPRIMIR (ver notas de diseño en INSTRUCCIONES.md):
 *   - Un collarin/disco que se ajusta al eje del motor (con tornillo
 *     prisionero M3 para fijarlo, permite reajustar el angulo si hace falta).
 *   - Una cavidad para un iman de neodimio pequeño (ej. 4mm dia x 2mm,
 *     comun y barato) cerca del borde del disco.
 *   - Un sensor Hall digital (ej. A3144 o similar) atornillado al chasis
 *     del motor, a unos pocos mm del disco, alineado para que el iman
 *     pase justo frente a el en cada vuelta.
 *
 * IMPORTANTE -- que SI resuelve y que NO:
 *   - Esto da un CERO REPETIBLE Y PRECISO DEL EJE DEL MOTOR, una vez por
 *     vuelta. No requiere guardar nada en flash (a diferencia del homing
 *     con el acelerometro): se re-hace en cada encendido, exactamente
 *     igual que una impresora 3D o maquina CNC que "hommea" cada vez que
 *     se prende. Es intencional, no una limitacion.
 *   - NO te dice por si solo en que vuelta estas dentro del recorrido
 *     completo del riel/husillo (el eje da muchas vueltas para mover la
 *     plataforma de un extremo a otro). Para el CERO ABSOLUTO DE TODO EL
 *     RECORRIDO, este indice magnetico se debe combinar con un limite
 *     fisico en un extremo del riel (switch mecanico/optico/Hall en el
 *     carro, no en el eje del motor) -- ver
 *     `Estado-del-arte/REFERENCIA DE POSICION ABSOLUTA/`. El indice
 *     magnetico del eje sirve para afinar ese punto con precision
 *     sub-paso una vez que ya sabes en que extremo estas.
 *
 * Conexionado del sensor Hall (ej. A3144, salida en colector abierto):
 *   VCC -> ESP32 3V3 (o 5V si el sensor lo requiere -- revisar tu modelo)
 *   GND -> ESP32 GND
 *   OUT -> ESP32 GPIO definido en HALL_PIN, con pull-up (interno o una
 *          resistencia externa de ~10k a 3V3) -- se activa en BAJO cuando
 *          el iman esta cerca (logica tipica de estos sensores).
 *
 * Conexionado del driver del motor: revisar tu driver especifico -- este
 * sketch asume una interfaz STEP/DIR/ENABLE generica.
 */

#include <Arduino.h>

// --- Pines -- AJUSTAR segun el cableado real de tu driver y sensor ---
#define STEP_PIN    26
#define DIR_PIN     27
#define ENABLE_PIN  25   // activo en BAJO en la mayoria de drivers (A4988/DRV8825/TMC2209)
#define HALL_PIN    34   // entrada digital, con pull-up

// --- Parametros de homing ---
#define DIR_HOMING          HIGH   // sentido de giro para buscar el iman -- AJUSTAR
#define STEP_DELAY_US_FAST  800    // velocidad de aproximacion rapida (menor = mas rapido)
#define STEP_DELAY_US_SLOW  3000   // velocidad de aproximacion fina (mas lento = mas preciso)
#define PASOS_RETROCESO     40     // pasos que retrocede antes de la aproximacion fina
#define MAX_PASOS_BUSQUEDA  4000   // limite de seguridad: si no encuentra el iman en
                                   // esta cantidad de pasos, aborta (evita que el motor
                                   // gire sin parar si el sensor/iman fallan)

long posicionPasos = 0; // posicion relativa al cero establecido por el homing

bool hallActivo() {
  // La mayoria de sensores Hall tipo interruptor son activos en BAJO
  // (colector abierto que se tira a GND cuando detecta el iman).
  return digitalRead(HALL_PIN) == LOW;
}

void unPaso(int delayMicros) {
  digitalWrite(STEP_PIN, HIGH);
  delayMicroseconds(delayMicros);
  digitalWrite(STEP_PIN, LOW);
  delayMicroseconds(delayMicros);
}

// Homing en dos etapas (igual que hace una CNC/impresora 3D): aproximacion
// rapida hasta el primer disparo, retroceso, y aproximacion lenta para un
// punto de disparo mucho mas repetible y preciso que con una sola pasada.
bool homingEjeMotor() {
  Serial.println("Iniciando homing del eje (buscando el iman)...");
  digitalWrite(DIR_PIN, DIR_HOMING);

  // --- Etapa 1: aproximacion rapida ---
  long pasosDados = 0;
  while (!hallActivo()) {
    unPaso(STEP_DELAY_US_FAST);
    pasosDados++;
    if (pasosDados > MAX_PASOS_BUSQUEDA) {
      Serial.println("ERROR: no se detecto el iman dentro del limite de pasos. Revisar sensor/iman/cableado.");
      return false;
    }
  }
  Serial.print("Iman detectado (aproximacion rapida) tras ");
  Serial.print(pasosDados);
  Serial.println(" pasos.");

  // --- Retroceder para volver a aproximarse desde el mismo lado, lento ---
  digitalWrite(DIR_PIN, !DIR_HOMING);
  for (int i = 0; i < PASOS_RETROCESO; i++) {
    unPaso(STEP_DELAY_US_FAST);
  }

  // --- Etapa 2: aproximacion lenta para precision ---
  digitalWrite(DIR_PIN, DIR_HOMING);
  pasosDados = 0;
  while (!hallActivo()) {
    unPaso(STEP_DELAY_US_SLOW);
    pasosDados++;
    if (pasosDados > PASOS_RETROCESO * 3) {
      Serial.println("ERROR: no se re-detecto el iman en la aproximacion lenta.");
      return false;
    }
  }

  Serial.println("Homing completo -- cero del eje establecido.");
  posicionPasos = 0;
  return true;
}

void setup() {
  Serial.begin(115200);
  while (!Serial) delay(10);

  pinMode(STEP_PIN, OUTPUT);
  pinMode(DIR_PIN, OUTPUT);
  pinMode(ENABLE_PIN, OUTPUT);
  pinMode(HALL_PIN, INPUT_PULLUP);

  digitalWrite(ENABLE_PIN, LOW); // habilita el driver (activo en bajo en la mayoria)

  Serial.println("=== Homing del husillo con iman + sensor Hall ===");
  Serial.println("Comandos: 'h' + Enter = re-homear | 'p' + Enter = imprimir posicion actual");

  homingEjeMotor();
}

void loop() {
  if (Serial.available() > 0) {
    char c = Serial.read();
    if (c == 'h' || c == 'H') {
      homingEjeMotor();
    } else if (c == 'p' || c == 'P') {
      Serial.print("Posicion actual (pasos desde el cero): ");
      Serial.println(posicionPasos);
    }
  }

  // Aca iria el resto del control normal del husillo (mover a una posicion
  // objetivo, etc.), incrementando/decrementando posicionPasos en cada
  // paso real que se de, igual que en cualquier control de stepper en
  // lazo abierto -- este sketch solo cubre el homing en si.
}

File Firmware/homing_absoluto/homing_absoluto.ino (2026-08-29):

/*
 * Homing / cero absoluto persistente para el pivote de flexo-extension
 * Sensor: MPU6050 (misma logica aplica al BNO055, ver nota al final)
 * Plataforma: ESP32 (I2C)
 *
 * IDEA (surge de la conversacion sobre "a = g*cos(theta)"):
 * la gravedad es una referencia absoluta que no se apaga ni deriva con el
 * tiempo. Si defines que "cero grados de flexion" corresponde a una
 * orientacion conocida respecto a la gravedad (ej. el pylon perfectamente
 * vertical), puedes usar el acelerometro para "anclar" ese cero -- y si
 * ademas guardas ese valor en la memoria flash del ESP32 (no en RAM), el
 * cero SOBREVIVE a apagar y encender el sistema. Eso es justo lo que
 * resuelve el pendiente de "referencia de posicion absoluta" para el eje
 * de rotacion (NO resuelve el eje de traslacion -- ahi sigue haciendo
 * falta un encoder absoluto o un switch de home, como ya quedo anotado).
 *
 * LIMITACION IMPORTANTE: esto solo es valido con el sistema QUIETO en el
 * momento de establecer el cero -- si hay movimiento, el acelerometro mide
 * gravedad + aceleracion dinamica mezcladas, y el "cero" quedaria mal
 * capturado. Es una rutina de HOMING (se hace una vez al empezar cada
 * sesion de ensayo), no una medicion continua de referencia absoluta.
 *
 * Comandos por Serial (escribe la letra y Enter en el Monitor Serie):
 *   z  -> Establece la posicion ACTUAL como cero absoluto (pide mantener
 *         quieto el pivote en la posicion de referencia ~1 s) y lo guarda
 *         en la memoria flash (Preferences/NVS del ESP32).
 *   c  -> Borra el cero guardado (vuelve a "sin calibrar").
 *
 * Salida CSV normal: roll,pitch (relativos al cero guardado, o crudos si
 * todavia no se estableció ningún cero), zero_set (0/1).
 *
 * Librerias requeridas: Adafruit MPU6050, Adafruit Unified Sensor,
 * Adafruit BusIO (Preferences.h ya viene incluida en el core de ESP32).
 *
 * Conexionado: igual que test_mpu6050.ino (VCC->3V3, GND->GND, SDA->GPIO21,
 * SCL->GPIO22, AD0->GND para direccion 0x68).
 */

#include <Wire.h>
#include <Adafruit_MPU6050.h>
#include <Adafruit_Sensor.h>
#include <Preferences.h>

Adafruit_MPU6050 mpu;
Preferences prefs;

#define GYRO_WEIGHT 0.98f
const char* NVS_NAMESPACE = "libra_home";

// --- Estado del filtro complementario (igual que en test_mpu6050.ino) ---
float roll = 0, pitch = 0;
unsigned long lastTime = 0;
float gyroBiasX = 0, gyroBiasY = 0, gyroBiasZ = 0;
const int CAL_SAMPLES = 200;

// --- Cero absoluto (cargado/guardado en flash) ---
float zeroRoll = 0, zeroPitch = 0;
bool zeroIsSet = false;
const int HOME_SAMPLES = 100; // ~1 s de promedio al establecer el cero

void calibrarGiro() {
  Serial.println("Calibrando giroscopio -- manten el sensor quieto...");
  double sumX = 0, sumY = 0, sumZ = 0;
  sensors_event_t a, g, temp;
  for (int i = 0; i < CAL_SAMPLES; i++) {
    mpu.getEvent(&a, &g, &temp);
    sumX += g.gyro.x; sumY += g.gyro.y; sumZ += g.gyro.z;
    delay(5);
  }
  gyroBiasX = sumX / CAL_SAMPLES;
  gyroBiasY = sumY / CAL_SAMPLES;
  gyroBiasZ = sumZ / CAL_SAMPLES;
}

void cargarZeroDesdeFlash() {
  prefs.begin(NVS_NAMESPACE, true); // solo lectura
  zeroIsSet = prefs.getBool("zero_set", false);
  if (zeroIsSet) {
    zeroRoll = prefs.getFloat("zero_roll", 0);
    zeroPitch = prefs.getFloat("zero_pitch", 0);
  }
  prefs.end();
}

void guardarZeroEnFlash(float r, float p) {
  prefs.begin(NVS_NAMESPACE, false); // lectura/escritura
  prefs.putFloat("zero_roll", r);
  prefs.putFloat("zero_pitch", p);
  prefs.putBool("zero_set", true);
  prefs.end();
  zeroRoll = r;
  zeroPitch = p;
  zeroIsSet = true;
}

void borrarZeroDeFlash() {
  prefs.begin(NVS_NAMESPACE, false);
  prefs.clear();
  prefs.end();
  zeroRoll = 0;
  zeroPitch = 0;
  zeroIsSet = false;
}

// Promedia SOLO el angulo derivado del acelerometro (sin el giro) durante
// HOME_SAMPLES muestras, y lo guarda como el nuevo cero absoluto.
void establecerZeroActual() {
  Serial.println("Estableciendo cero absoluto -- MANTEN EL PIVOTE QUIETO en la posicion de referencia...");
  double sumRoll = 0, sumPitch = 0;
  sensors_event_t a, g, temp;

  for (int i = 0; i < HOME_SAMPLES; i++) {
    mpu.getEvent(&a, &g, &temp);
    float r = atan2(a.acceleration.y, a.acceleration.z) * 180.0 / PI;
    float p = atan2(-a.acceleration.x, sqrt(a.acceleration.y * a.acceleration.y + a.acceleration.z * a.acceleration.z)) * 180.0 / PI;
    sumRoll += r;
    sumPitch += p;
    delay(10);
  }

  float r0 = sumRoll / HOME_SAMPLES;
  float p0 = sumPitch / HOME_SAMPLES;
  guardarZeroEnFlash(r0, p0);

  Serial.print("Cero absoluto guardado en flash: roll0=");
  Serial.print(r0, 2);
  Serial.print("  pitch0=");
  Serial.println(p0, 2);
}

void setup() {
  Serial.begin(115200);
  while (!Serial) delay(10);

  Serial.println("=== Homing / cero absoluto persistente (MPU6050) ===");

  Wire.begin(21, 22);

  if (!mpu.begin(0x68, &Wire)) {
    Serial.println("ERROR: no se detecto el MPU6050. Revisar alimentacion, SDA/SCL y direccion I2C.");
    while (1) { delay(1000); }
  }

  Serial.println("MPU6050 detectado correctamente.");

  mpu.setAccelerometerRange(MPU6050_RANGE_8_G);
  mpu.setGyroRange(MPU6050_RANGE_500_DEG);
  mpu.setFilterBandwidth(MPU6050_BAND_21_HZ);

  delay(300);
  calibrarGiro();

  cargarZeroDesdeFlash();
  if (zeroIsSet) {
    Serial.print("Cero absoluto cargado de la memoria flash: roll0=");
    Serial.print(zeroRoll, 2);
    Serial.print("  pitch0=");
    Serial.println(zeroPitch, 2);
  } else {
    Serial.println("No hay ningun cero guardado todavia.");
  }
  Serial.println("Comandos: 'z' + Enter = establecer cero actual | 'c' + Enter = borrar cero guardado");

  // Inicializar el filtro con el angulo crudo del acelerometro
  sensors_event_t a, g, temp;
  mpu.getEvent(&a, &g, &temp);
  roll  = atan2(a.acceleration.y, a.acceleration.z) * 180.0 / PI;
  pitch = atan2(-a.acceleration.x, sqrt(a.acceleration.y * a.acceleration.y + a.acceleration.z * a.acceleration.z)) * 180.0 / PI;
  lastTime = millis();

  Serial.println("roll,pitch,roll_abs,pitch_abs,zero_set");
}
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

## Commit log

2026-08-07 Agrega documentacion inicial del proyecto: estado del arte, reportes semanales y plan de trabajo
2026-08-07 Reorganiza README y agrega fuente de simulador de marcha (ref. 32)
    Reescribe el README con descripcion, objetivos y estructura del
    repositorio; mueve el PDF de la referencia [32] a una nueva carpeta
    Estado-del-arte/SIMULADOR DE MARCHA.
2026-08-07 Reordena estructura del repo: reportes bajo Reportes-Semanales/, documentos de proyecto en la raiz, fotos propias en Evidencias/
    - Revierte el aplanado accidental de Reportes-Semanales/S1 -> S1/ en la raiz
    - Mueve Revision bibliografica y Pendientes.md de vuelta a la raiz (documentos de todo el proyecto, no de una sola semana)
    - Mueve las fotos del simulador y del metodo de marcadores M1-M4 a Evidencias/simulador/
    - Elimina los .docx (Informe Semanal y Reporte de Avance); de ahora en adelante los reportes se mantienen solo en .md
    - Embebe las 5 fotos directamente en la revision bibliografica (Seccion 8 y 8.2)
    - Actualiza el arbol de carpetas en el README
2026-08-07 Deja de versionar .claude/ (configuracion interna de la herramienta, no aporta al repo)
2026-08-07 Mueve la revision bibliografica a Estado-del-arte/ y Pendientes.md a cada semana
    - Revision bibliografica - Semana 1-2.md pasa a Estado-del-arte/: es el documento de sintesis de todo ese material, tiene mas sentido ahi que en la raiz o dentro de una semana especifica
    - Pendientes.md pasa a ser por semana (Reportes-Semanales/S1/Pendientes.md), ya que se va actualizando semana a semana; al cerrar una semana los pendientes abiertos se trasladan al Pendientes.md de la siguiente
    - Corrige rutas de imagenes (Evidencias/ ahora se referencia con ../ desde Estado-del-arte/) y todos los enlaces/menciones en README e Informe Semanal
2026-08-07 Corrige framing: el alcance del Objetivo 1 se aclaro, no se redefinio; deja abierta la posibilidad de rediseno mecanico para los nuevos sensores
2026-08-08 Limpia revision bibliografica: quita narracion de proceso (verificacion ISO, actualizaciones de busqueda) y decisiones/relevancia redundantes en 8.2; tablas ISO 10328 sin emojis ni tachones
2026-08-08 Quita framing de aclaracion con fecha en Secc 8: pasa a nota de contexto directa
2026-08-08 Secc 8.1: mismo tratamiento, nota de contexto directa sin fecha ni nombre
2026-08-08 Secc 10: convierte requerimientos tecnicos de parrafos largos a tabla por componente, sin flechas
2026-08-08 Informe Semanal: junta 8 actividades en 6, quita formato Que/Como/Para que/Resultado y nombres propios
2026-08-08 Resumen Ejecutivo: menos especifico, sin cifras exactas ni mencion de posible rediseno del Objetivo 1
2026-08-08 Dificultades: generaliza acceso a ISO 10328, agrega problema de acceso al sistema de bibliotecas PUCP
2026-08-08 Actividades siguiente semana: agrega diagrama de bloques, seleccion de sensores, material de absorcion de impacto y boceto de ubicacion de componentes
2026-08-08 Actividades Realizadas 1-5: quita cifras exactas, describe que representan (ej. rangos de resistencia que limitan la seleccion de sensores)
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2026-08-08 Reporte de Avance: resume actividades y situaciones surgidas, consistente con Informe Semanal (sin cifras exactas, agrega problema de bibliotecas)
2026-08-08 A5: quita Confirmado tajante, deja claro que es informal y pendiente de validar
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2026-08-08 Actualiza causa del problema de bibliotecas: suspension por matricula 2026-2 (4-13 agosto), confirmado por el sistema de bibliotecas PUCP
2026-08-15 Semana 2: arquitectura de sensores por DOF, integración AMTI y reportes S2
    - Documenta decisión de arquitectura de sensado por DOF (reunión con asesor)
    - Agrega manuales técnicos AMTI (Gen5 User Manual, manual de operación)
    - Agrega diagrama de arquitectura de sensores y resumen narrativo de la semana
    - Crea Informe Semanal y Reporte de Avance de S2
    - Actualiza Pendientes.md con resolución IMU/encoder y pinout AMTI confirmado
    - Enlaza el diagrama en Resumen-Semana2.md via raw.githubusercontent.com
2026-08-19 Reorganiza SENSORES DE FUERZA en PYLON/ y GRF-AMTI/; agrega comparativa de celdas de carga y presentación de sensores
    Separa el material bibliográfico de la celda de carga del pylon (strain gauge,
    sensor magnético, comparativa de candidatas) del material de la plataforma
    de fuerza AMTI (manuales, pinout), ya que son dos líneas de trabajo distintas
    desde la arquitectura de sensores por DOF de la S2. Incorpora al repo dos
    archivos de la sesión de investigación de sensores que quedaron sin commitear:
    la comparativa de sensores de fuerza axial (la candidata TAL107F-10kg resultó
    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
2026-08-22 Semana 3: comparativa de sensores por variable sensada y simulacion estructural de la placa (5 corridas ANSYS)
    - Sensores: distancia (TF-Luna) y angulo (AS5600) definidos; IMU probable (MPU6050); fuerza sigue abierta, buscando proveedores peruanos
    - Simulacion ANSYS: 15/20/25 mm solidos, 20 mm con vaciado central, 15 mm con refuerzo en cruz - solo 25 mm solida cumple factor de seguridad >1
    - Agrega Informe Semanal y Reporte de Avance S3 (formato PUCP) y Resumen-Semana3.md
    - Agrega configuracion de material/impresion (Excel) usada como insumo de la simulacion
    [LIBRA_Config_Impresion_y_Calculo_Material.xlsx]
2026-08-29 Semana 4: firmware de pruebas IMU/homing, evidencias de banco y ANSYS, avance de arquitectura de referencia absoluta
    [LIBRA_Config_Impresion_y_Calculo_Material.xlsx]
2026-09-26 Semana 8: PCB (placa superior y breakout BNO055), calibracion HX711, pruebas ToF VL53L1X, estado del arte (IMU y control de fuerza), collarin de imanes
    [collarin_imanes.step, collarin_imanes.stl, tof_20cm_40cm_prueba1.csv]
2026-10-03 Semana 9: diagnostico y reparacion de conexion del BNO055, calibracion de acelerometro, prueba de linealidad 0-60 grados con soporte indexado, filtro de correccion lineal, diseno CAD preliminar del a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
    [PCB_LIBRA_IMU.step, angulos_10deg_recal_0deg_01.csv, angulos_10deg_recal_0deg_03.csv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]
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2026-11-07 Semana 12: integracion de sensores, correccion lineal del roll en firmware BNO055, caja PCB v3 snap, cable IMU, ensamble final y renders, reporte S12
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
